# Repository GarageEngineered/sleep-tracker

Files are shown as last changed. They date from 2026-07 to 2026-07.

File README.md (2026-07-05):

# sleep-tracker
Everything needed to create a sleep or fitness tracker at home

Overview:
The point of this project is to see how realistic it is to make a DIY sleep/fitness tracker with little to no relevant experience. A major aspect of this project is testing the abilities of AI. Claude was used to help define hardware, facilitate wiring and writing software.

Parts List:

Processor: NRF52840 https://www.amazon.com/Teyleten-Robot-Development-Bluetooth-Management/dp/B0CYLNZ6V4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

PPG sensor (HR, HRV, Sp02): MAX30102 I suggest buying multiple as I broke a few trying to assemble the device. https://www.amazon.com/Diitao-MAX30102-Detection-Concentration-Calculation/dp/B0B2R9WNVP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

IMU (movement): LSM6DS3 https://www.amazon.com/LSM6DS3-Accelerometer-Gyroscope-Temperature-Interface/dp/B0FKT9ZR2X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

Temperature: TMP117 The one I bought is no longer available on amazon. Here is the link to their direct site https://www.sparkfun.com/sparkfun-high-precision-temperature-sensor-tmp117-qwiic.html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

Batery: 503035 3.7v https://www.amazon.com/Winfox-Rechargeable-Connector-Bluetooth-Portable/dp/B0GDQLLF12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

Resistors: 2 10k Ohm

Wire: 28 Ga, I reccomend getting at least 4 colors (1 for each of the following 3.3V, GND, SCL, SDA)

20mm watch band: https://www.amazon.com/WOCCI-Adjustable-Nylon-Watch-Release/dp/B09YTPMRJY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

Housing: I printed mine on an Ender 3-V2 in PLA with a 0.4mm nozzle

Metal slug: I cut the top off of a stainless bolt with a 7/16" head

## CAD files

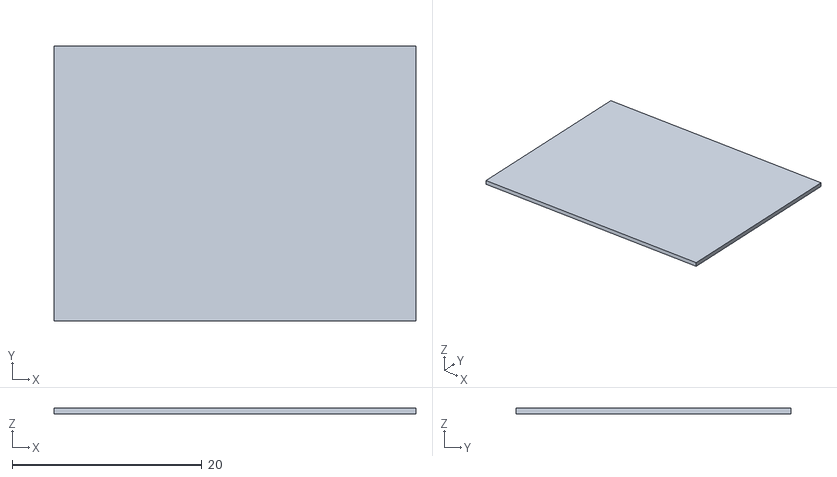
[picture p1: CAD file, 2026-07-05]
Housing/housing_14_cover.stl
38.1 x 29.0 x 0.61

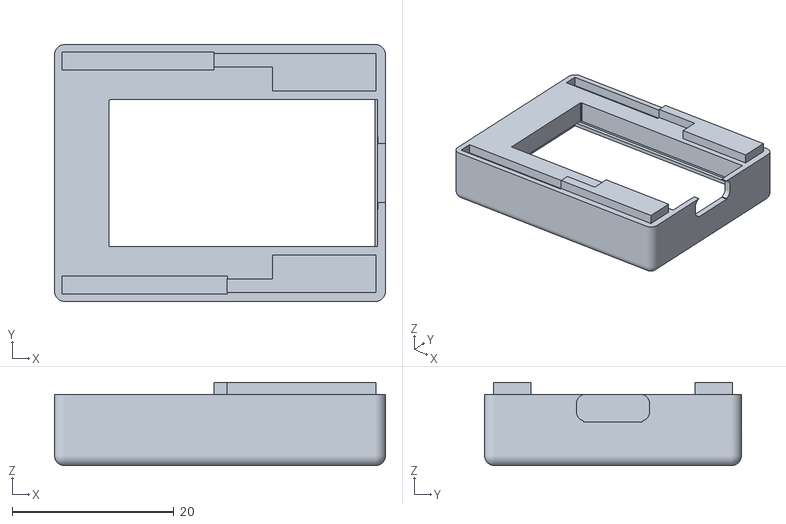
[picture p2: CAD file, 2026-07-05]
Housing/housing_14_top.stl
40.9 x 31.7 x 10.3

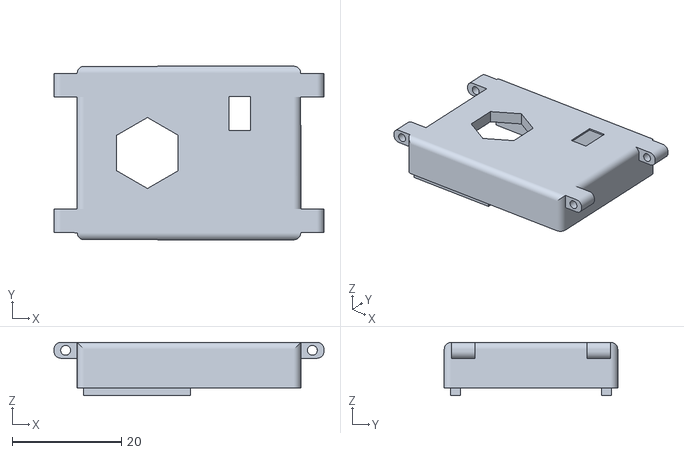
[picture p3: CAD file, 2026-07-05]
Housing/housing_14_bottom.stl
49.4 x 31.7 x 9.75

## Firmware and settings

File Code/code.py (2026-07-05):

"""
Fitness Tracker - CircuitPython
Hardware: SuperMini NRF52840, MAX30102, LSM6DS3, TMP117
Features: HR, SpO2, HRV, Steps, Skin Temp, Sleep Detection, CSV Logging -> BLE UART

Wiring:
  MAX30102  -> 3V3, GND, SDA, SCL
  LSM6DS3   -> 3V3, GND, SDA, SCL
  TMP117    -> 3V3, GND, SDA, SCL
  Pull-ups: 10k ohm from 3V3 to SDA and SCL

Libraries needed in /lib:
  adafruit_ble/
  adafruit_lsm6ds/
  adafruit_register/
  adafruit_tmp117.mpy

BLE protocol:
  On connect, phone sends: SET_TIME:<unix_timestamp>
  Board streams CSV log when phone sends: GET_LOG
  Board clears log when phone sends: CLEAR_LOG
  Normal data: HR:<n>,SpO2:<n>,HRV:<n>,Steps:<n> every 2s

State machine:
  awake       -> full sample rate, BLE on, streaming
      |
      |-- sleep window + still 5 min --> sleep
      |-- not sleep window + still 10 min --> unattended
      |
  sleep       -> full sample rate, BLE OFF, logging only
      |
      |-- movement + outside sleep window --> awake
      |
  unattended  -> HR only every 5 min, BLE OFF, no logging
      |
      |-- movement confirmed for 2 min --> awake

Power profile (approx):
  awake:       25-35mA  (BLE on, all sensors)
  sleep:        8-12mA  (BLE off, all sensors)
  unattended:   3-5mA   (BLE off, HR duty cycled)
"""

import time
import math
import board
import busio
import digitalio
from adafruit_ble import BLERadio
from adafruit_ble.advertising.standard import ProvideServicesAdvertisement
from adafruit_ble.services.nordic import UARTService
from adafruit_lsm6ds.lsm6ds33 import LSM6DS33 as LSM6DS3
from adafruit_lsm6ds import Rate, AccelRange
import supervisor
import microcontroller
import adafruit_tmp117
import analogio

# Capture USB state at boot for disconnect detection
_usb_was_connected = supervisor.runtime.usb_connected

# Battery voltage monitoring
# Multiplier of 40.41 validated against multimeter reading for this specific board
BAT_MULTIPLIER = 40.41
_bat_pin = analogio.AnalogIn(board.BAT_VOLT)
_bat_smooth = 0.0  # smoothed battery voltage

LOG_FILE = "/data.csv"
BOOT_LOG_FILE = "/boot_log.txt"


def _boot_log(msg):
    """Append a boot-stage milestone to a file so progress can be inspected
    after a battery-only run with no serial console attached."""
    try:
        with open(BOOT_LOG_FILE, "a") as f:
            f.write("{} | usb={}\n".format(msg, supervisor.runtime.usb_connected))
    except OSError as e:
        print("boot log write failed:", e)


def _i2c_bus_recovery():
    """Manually clock SCL to free a slave that's stuck holding SDA low.
    On battery, MAX30102 (powered from RAW) can power up out of sync with
    the IMU/TMP117 (powered from 3V3), leaving it mid-transaction with SDA
    latched low — which hangs busio.I2C() before it can even finish init.
    This bit-bangs up to 9 clock pulses (the max a stuck I2C slave can be
    waiting on) and issues a STOP condition to force the bus free."""
    scl = digitalio.DigitalInOut(board.SCL)
    sda = digitalio.DigitalInOut(board.SDA)
    scl.direction = digitalio.Direction.OUTPUT
    sda.direction = digitalio.Direction.INPUT
    scl.value = True

    for _ in range(9):
        if sda.value:
            break
        scl.value = False
        time.sleep(0.00005)
        scl.value = True
        time.sleep(0.00005)

    # Issue a STOP condition: SDA low-to-high while SCL is high
    sda.direction = digitalio.Direction.OUTPUT
    sda.value = False
    time.sleep(0.00005)
    scl.value = True
    time.sleep(0.00005)
    sda.value = True
    time.sleep(0.00005)

    scl.deinit()
    sda.deinit()

# ─────────────────────────────────────────────
#  MAX30102 Driver
# ─────────────────────────────────────────────

MAX30102_ADDR   = 0x57
REG_FIFO_WR_PTR = 0x04
REG_OVF_COUNTER = 0x05
REG_FIFO_RD_PTR = 0x06
REG_FIFO_DATA   = 0x07
REG_FIFO_CONFIG = 0x08
REG_MODE_CONFIG = 0x09
REG_SPO2_CONFIG = 0x0A
REG_LED1_PA     = 0x0C
REG_LED2_PA     = 0x0D

class MAX30102:
    def __init__(self, i2c):
        self.i2c = i2c
        self._setup()

    def _write(self, reg, value):
        while not self.i2c.try_lock():
            pass
        try:
            self.i2c.writeto(MAX30102_ADDR, bytes([reg, value]))
        finally:
            self.i2c.unlock()

    def _read(self, reg, length=1):
        while not self.i2c.try_lock():
            pass
        try:
            buf = bytearray(length)
            self.i2c.writeto_then_readfrom(MAX30102_ADDR, bytes([reg]), buf)
        finally:
            self.i2c.unlock()
        return buf

    def _setup(self):
        self._write(REG_MODE_CONFIG, 0x40)
        time.sleep(0.1)
        self._write(REG_MODE_CONFIG, 0x03)
        self._write(REG_SPO2_CONFIG, 0x27)
        self._write(REG_FIFO_CONFIG, 0x1F)  # no averaging, rollover enabled
        self._write(REG_LED1_PA,     0x3F)  # RED LED — validated for wrist use
        self._write(REG_LED2_PA,     0x3F)  # IR LED — validated for wrist use
        self._write(REG_FIFO_WR_PTR, 0x00)
        self._write(REG_OVF_COUNTER, 0x00)
        self._write(REG_FIFO_RD_PTR, 0x00)

    def shutdown(self):
        """Put MAX30102 into low power shutdown mode."""
        self._write(REG_MODE_CONFIG, 0x80)

    def wakeup(self):
        """Wake MAX30102 from shutdown and restore HR+SpO2 mode."""
        self._write(REG_MODE_CONFIG, 0x03)

    def read_fifo_sample(self):
        wr = self._read(REG_FIFO_WR_PTR)[0]
        rd = self._read(REG_FIFO_RD_PTR)[0]
        if wr == rd:
            return None
        data = self._read(REG_FIFO_DATA, 6)
        red = ((data[0] & 0x03) << 16) | (data[1] << 8) | data[2]
        ir  = ((data[3] & 0x03) << 16) | (data[4] << 8) | data[5]
        return red, ir


# ─────────────────────────────────────────────
#  Heart Rate & HRV Processor
#
#  Pipeline:
#  1. IIR bandpass filter isolates heartbeat signal
#     from DC baseline and high-frequency noise
#  2. Zero-crossing derivative peak detection
#  3. Wall-clock RR interval measurement
#  4. Outlier rejection + RMSSD computation
#
#  Key values validated via shell testing:
#    LP_ALPHA 0.80 — best HR accuracy vs noise
#    REFRACTORY_MS 700 — cleanly skips dicrotic notch
#    IR_THRESHOLD 10000 — separates finger-on (~130k)
#                         from finger-off (~1600)
# ─────────────────────────────────────────────

class HRProcessor:
    SAMPLE_RATE_HZ  = 100
    MS_PER_SAMPLE   = 10
    REFRACTORY_MS   = 700      # validated — skips dicrotic notch (~400ms after peak)
    SIGNAL_LOSS_S   = 3.0
    IR_THRESHOLD    = 10000    # finger-off ~1600, finger-on ~130000
    RR_OUTLIER_PCT  = 0.25     # reject RR > 25% from recent mean
    RR_WARMUP       = 4        # discard first N intervals while amplitude buffer settles

    # IIR filter coefficients (validated via shell test)
    HP_ALPHA        = 0.95     # high-pass: removes DC baseline
    LP_ALPHA        = 0.80     # low-pass: removes noise, preserves heartbeat

    ACQUIRE_SAMPS   = 200      # samples to let filter settle after finger placement

    def __init__(self):
        self._sample_count  = 0
        self._rr_list       = []
        self.bpm            = 0
        self.rmssd          = 0
        self._last_signal   = time.monotonic()
        self._acquire_count = 0

        # Filter state
        self._hp_prev_raw   = 0.0
        self._hp_prev_out   = 0.0
        self._lp_prev       = 0.0

        # Peak detection state
        self._last_peak_ms  = 0      # wall-clock ms of last peak (RR timing)
        self._rr_warmup     = 0      # warmup interval counter
        self._prev_filtered = 0.0
        self._prev_deriv    = 0.0
        self._peak_amp_buf  = []     # recent peak amplitudes for adaptive threshold

    def _filter(self, raw):
        """Two-stage IIR bandpass filter."""
        hp = self.HP_ALPHA * (self._hp_prev_out + raw - self._hp_prev_raw)
        self._hp_prev_raw = raw
        self._hp_prev_out = hp
        lp = (1.0 - self.LP_ALPHA) * hp + self.LP_ALPHA * self._lp_prev
        self._lp_prev = lp
        return lp

    def update(self, ir):
        """Call once per sample."""
        self._sample_count += 1

        if ir >= self.IR_THRESHOLD:
            self._last_signal = time.monotonic()
            self._acquire_count += 1
        else:
            if time.monotonic() - self._last_signal > self.SIGNAL_LOSS_S:
                self._reset()
            elif time.monotonic() - self._last_signal > 0.5:
                # Signal dropping — reset acquire so filter re-settles on replacement
                self._acquire_count = 0
            return

        filtered = self._filter(float(ir))

        # Let filter settle after finger placement
        if self._acquire_count == self.ACQUIRE_SAMPS:
            self._peak_amp_buf = []   # clear amplitude buffer at end of acquisition
        if self._acquire_count < self.ACQUIRE_SAMPS:
            self._prev_filtered = filtered
            self._prev_deriv = 0.0
            return

        deriv = filtered - self._prev_filtered
        now_ms = time.monotonic_ns() // 1_000_000

        # Refractory check — wall-clock based, immune to burst read timing
        refractory_ok = (self._last_peak_ms == 0 or
                         (now_ms - self._last_peak_ms) > self.REFRACTORY_MS)

        if self._prev_deriv > 0 and deriv <= 0 and refractory_ok:
            peak_val = self._prev_filtered

            # Adaptive amplitude threshold — peak must exceed 30% of recent mean
            if self._peak_amp_buf:
                mean_amp = sum(self._peak_amp_buf) / len(self._peak_amp_buf)
                if peak_val < mean_amp * 0.30:
                    self._prev_filtered = filtered
                    self._prev_deriv = deriv
                    return

            if peak_val > 0:
                if self._last_peak_ms > 0:
                    rr_ms = now_ms - self._last_peak_ms

                    if 333 < rr_ms < 2000:
                        if self._rr_warmup < self.RR_WARMUP:
                            self._rr_warmup += 1
                        else:
                            accept = True
                            if len(self._rr_list) >= 4:
                                mean_rr = sum(self._rr_list) / len(self._rr_list)
                                if abs(rr_ms - mean_rr) > mean_rr * self.RR_OUTLIER_PCT:
                                    accept = False
                            if accept:
                                self._rr_list.append(rr_ms)
                                if len(self._rr_list) > 12:
                                    self._rr_list.pop(0)
                                self._compute()

                self._peak_amp_buf.append(abs(peak_val))
                if len(self._peak_amp_buf) > 8:
                    self._peak_amp_buf.pop(0)
                self._last_peak_ms = now_ms

        self._prev_filtered = filtered
        self._prev_deriv = deriv

    def _reset(self):
        self.bpm            = 0
        self.rmssd          = 0
        self._rr_list       = []
        self._acquire_count = 0
        self._hp_prev_raw   = 0.0
        self._hp_prev_out   = 0.0
        self._lp_prev       = 0.0
        self._last_peak_ms  = 0
        self._rr_warmup     = 0
        self._prev_filtered = 0.0
        self._prev_deriv    = 0.0
        self._peak_amp_buf  = []

    def _compute(self):
        if len(self._rr_list) < 4:
            return
        mean_rr = sum(self._rr_list) / len(self._rr_list)
        if mean_rr <= 0:
            return
        bpm = round(60000 / mean_rr)
        if not (30 <= bpm <= 180):
            return
        self.bpm = bpm
        sq_diffs = [(self._rr_list[i+1] - self._rr_list[i])**2
                    for i in range(len(self._rr_list)-1)]
        self.rmssd = round((sum(sq_diffs) / len(sq_diffs)) ** 0.5)


# ─────────────────────────────────────────────
#  SpO2 Processor
# ─────────────────────────────────────────────

class SpO2Processor:
    WINDOW    = 200   # larger window for stable R ratio
    MIN_AC_IR = 50    # minimum IR AC amplitude for valid reading
    SMOOTH    = 0.3   # smoothing factor — prevents single-sample jumps

    def __init__(self):
        self._red_buf   = []
        self._ir_buf    = []
        self.spo2       = 0
        self._prev_spo2 = 0

    def update(self, red, ir):
        self._red_buf.append(red)
        self._ir_buf.append(ir)
        if len(self._red_buf) > self.WINDOW:
            self._red_buf.pop(0)
            self._ir_buf.pop(0)
        if len(self._red_buf) == self.WINDOW:
            self._compute()

    def _compute(self):
        red_dc = sum(self._red_buf) / self.WINDOW
        ir_dc  = sum(self._ir_buf)  / self.WINDOW
        if ir_dc == 0 or red_dc == 0:
            return
        red_ac = max(self._red_buf) - min(self._red_buf)
        ir_ac  = max(self._ir_buf)  - min(self._ir_buf)
        if ir_ac < self.MIN_AC_IR or red_ac == 0:
            return
        R = (red_ac / red_dc) / (ir_ac / ir_dc)
        if not (0.4 <= R <= 1.2):
            return
        spo2 = -45.060 * R * R + 30.354 * R + 94.845
        spo2 = max(70, min(100, round(spo2)))
        if self._prev_spo2 == 0:
            self._prev_spo2 = spo2
        smoothed = round(self._prev_spo2 * (1 - self.SMOOTH) + spo2 * self.SMOOTH)
        self._prev_spo2 = smoothed
        self.spo2 = smoothed


# ─────────────────────────────────────────────
#  Movement Tracker
# ─────────────────────────────────────────────

class MovementTracker:
    GRAVITY        = 9.8
    WINDOW_SECS    = 10
    SAMPLE_RATE    = 10
    WINDOW_SIZE    = WINDOW_SECS * SAMPLE_RATE
    BASELINE_SIZE  = 300

    def __init__(self):
        self._mag_buf     = []
        self.score        = 0.0
        self._day_scores  = []
        self.day_baseline = 0.5

    def update(self, ax, ay, az, is_daytime):
        mag = math.sqrt(ax*ax + ay*ay + az*az)
        dynamic = abs(mag - self.GRAVITY)
        self._mag_buf.append(dynamic)
        if len(self._mag_buf) > self.WINDOW_SIZE:
            self._mag_buf.pop(0)
        if len(self._mag_buf) >= 2:
            mean = sum(self._mag_buf) / len(self._mag_buf)
            variance = sum((x - mean)**2 for x in self._mag_buf) / len(self._mag_buf)
            self.score = math.sqrt(variance)
        if is_daytime and self.score > 0:
            self._day_scores.append(self.score)
            if len(self._day_scores) > self.BASELINE_SIZE:
                self._day_scores.pop(0)
            if len(self._day_scores) >= 10:
                self.day_baseline = sum(self._day_scores) / len(self._day_scores)

    @property
    def is_still(self):
        return self.score < (self.day_baseline * 0.2)

    @property
    def is_active(self):
        return self.score > (self.day_baseline * 0.35)


# ─────────────────────────────────────────────
#  Sleep & Unattended State Machine
# ─────────────────────────────────────────────

class SleepTracker:
    AWAKE      = "awake"
    LIGHT      = "light"
    DEEP       = "deep"
    REM        = "rem"
    UNATTENDED = "unattended"

    SLEEP_ONSET_MINS      = 5
    UNATTENDED_ONSET_MINS = 10
    WAKE_CONFIRM_MINS     = 2

    def __init__(self):
        self.state           = self.AWAKE
        self._still_minutes  = 0
        self._active_minutes = 0
        self._sleep_onset_hr = None

    def update(self, hour, is_still, is_active, bpm, rmssd):
        is_sleep_window = (hour >= 21 or hour < 9)

        if self.state == self.AWAKE:
            if is_still:
                self._still_minutes += (1 / 60.0)
                if is_sleep_window and self._still_minutes >= self.SLEEP_ONSET_MINS:
                    self.state = self.LIGHT
                    self._sleep_onset_hr = bpm if bpm > 0 else 60
                    self._still_minutes = 0
                elif not is_sleep_window and self._still_minutes >= self.UNATTENDED_ONSET_MINS:
                    self.state = self.UNATTENDED
                    self._still_minutes = 0
            else:
                self._still_minutes = 0

        elif self.state in (self.LIGHT, self.DEEP, self.REM):
            if not is_still and not is_sleep_window:
                self.state = self.AWAKE
                self._sleep_onset_hr = None
                self._still_minutes = 0
                return self.state
            if bpm > 0 and rmssd > 0 and self._sleep_onset_hr:
                hr_ratio = bpm / self._sleep_onset_hr
                if hr_ratio < 0.88 and rmssd > 40:
                    self.state = self.DEEP
                elif hr_ratio > 0.95 and rmssd < 25:
                    self.state = self.REM
                else:
                    self.state = self.LIGHT
            elif is_still:
                self.state = self.LIGHT

        elif self.state == self.UNATTENDED:
            if is_active:
                self._active_minutes += (1 / 60.0)
                if self._active_minutes >= self.WAKE_CONFIRM_MINS:
                    self.state = self.AWAKE
                    self._active_minutes = 0
                    self._still_minutes = 0
            else:
                self._active_minutes = 0

        return self.state

    @property
    def is_sleep(self):
        return self.state in (self.LIGHT, self.DEEP, self.REM)

    @property
    def is_unattended(self):
        return self.state == self.UNATTENDED

    @property
    def ble_should_be_off(self):
        return self.state in (self.LIGHT, self.DEEP, self.REM, self.UNATTENDED)

    @property
    def log_state_str(self):
        return self.state


# ─────────────────────────────────────────────
#  Data Logger
# ─────────────────────────────────────────────

class DataLogger:
    FLUSH_INTERVAL = 60
    MAX_BUF        = 120   # cap buffers to limit RAM usage

    def __init__(self):
        self._hr_buf     = []
        self._spo2_buf   = []
        self._hrv_buf    = []
        self._mov_buf    = []
        self._last_flush = time.monotonic()
        self._ensure_header()

    def _ensure_header(self):
        try:
            with open(LOG_FILE, "r") as f:
                if f.read(3) == "ts,":
                    return
        except OSError:
            pass
        with open(LOG_FILE, "w") as f:
            f.write("ts,hr,spo2,hrv,steps,mov,temp,bat,state\n")

    def add_sample(self, hr, spo2, hrv, movement_score):
        if hr > 0:
            self._hr_buf.append(hr)
            if len(self._hr_buf) > self.MAX_BUF:
                self._hr_buf.pop(0)
        if spo2 > 0:
            self._spo2_buf.append(spo2)
            if len(self._spo2_buf) > self.MAX_BUF:
                self._spo2_buf.pop(0)
        if hrv > 0:
            self._hrv_buf.append(hrv)
            if len(self._hrv_buf) > self.MAX_BUF:
                self._hrv_buf.pop(0)
        self._mov_buf.append(movement_score)
        if len(self._mov_buf) > self.MAX_BUF:
            self._mov_buf.pop(0)

    def _median(self, buf):
        if not buf:
            return 0
        s = sorted(buf)
        mid = len(s) // 2
        return s[mid] if len(s) % 2 else (s[mid-1] + s[mid]) // 2

    def flush(self, unix_ts, steps, sleep_state, skin_temp=0.0, bat_v=0.0):
        now = time.monotonic()
        if now - self._last_flush < self.FLUSH_INTERVAL:
            return False
        hr   = self._median(self._hr_buf)
        spo2 = self._median(self._spo2_buf)
        hrv  = self._median(self._hrv_buf)
        mov  = round(sum(self._mov_buf) / len(self._mov_buf), 4) if self._mov_buf else 0
        try:
            with open(LOG_FILE, "a") as f:
                f.write("{},{},{},{},{},{},{},{},{}\n".format(
                    unix_ts, hr, spo2, hrv, steps, mov, skin_temp, bat_v, sleep_state))
        except OSError as e:
            print("Log write error:", e)
        self._hr_buf.clear()
        self._spo2_buf.clear()
        self._hrv_buf.clear()
        self._mov_buf.clear()
        self._last_flush = now
        return True

    def stream_log(self, uart):
        try:
            with open(LOG_FILE, "r") as f:
                while True:
                    chunk = f.read(100)
                    if not chunk:
                        break
                    uart.write(chunk.encode())
                    time.sleep(0.05)
            uart.write(b"END_LOG\n")
        except OSError:
            uart.write(b"NO_LOG\n")

    def clear_log(self):
        with open(LOG_FILE, "w") as f:
            f.write("ts,hr,spo2,hrv,steps,mov,temp,bat,state\n")


# ─────────────────────────────────────────────
#  Time Manager
# ─────────────────────────────────────────────

class TimeManager:
    def __init__(self):
        self._offset = 0
        self._synced = False

    def sync(self, unix_ts):
        self._offset = unix_ts - time.monotonic()
        self._synced = True
        print("Time synced. Unix ts:", unix_ts)

    @property
    def unix(self):
        return int(time.monotonic() + self._offset)

    @property
    def hour(self):
        if not self._synced:
            return 12
        return (self.unix % 86400) // 3600

    @property
    def is_daytime(self):
        return 6 <= self.hour < 21


# ─────────────────────────────────────────────
#  BLE Manager
# ─────────────────────────────────────────────
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

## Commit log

2026-07-05 Housing STL files
    [housing_14_bottom.stl, housing_14_cover.stl, housing_14_top.stl]
2026-07-05 Current code for the device
